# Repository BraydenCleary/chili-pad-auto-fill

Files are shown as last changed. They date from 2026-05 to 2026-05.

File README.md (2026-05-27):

# Chili Pad Auto-Fill

Automatically refills your [Chili Sleep](https://chilisleep.com) device's water reservoir once a day using an ESP32, a peristaltic pump, and a water level sensor. Just plug it in each morning and it checks the level and tops up if needed — no more waking up to a dry pad.

---

## How It Works

On power-up the ESP32 checks the water level sensor. If the reservoir is low it runs the peristaltic pump until the sensor reads full (or hits the 30-second safety timeout). Then it sleeps for 24 hours and repeats. Plug it in whenever you want the daily check to happen.

---

## Parts List

| Part | Notes |
|---|---|
| ESP32 dev board (WROOM) | Any standard 38-pin ESP32 works |
| [Kamoer 12V peristaltic pump](https://www.kamoer.com) | KPP-DC-S108 or similar |
| CQRobot optical water level sensor | Has a 3V/5V selector switch — set to 3V |
| 1-channel relay module (high/low level trigger) | Songle SRD-05VDC or similar |
| 12V 2A DC wall adapter | Barrel connector, cut off and strip the wires |
| Silicone tubing | Match your pump's tube diameter |
| WAGO 222-412 lever connectors | For joining pump and adapter ground wires |
| Male-to-male jumper wires | For connecting pump terminals to relay |
| Female-to-male jumper wires | For connecting sensor and relay to ESP32 |

---

## Wiring

### Sensor → ESP32
| Sensor wire | ESP32 pin |
|---|---|
| Red (VCC) | 3V3 |
| Black (GND) | GND |
| Green (signal) | P23 |

⚠️ Make sure the selector switch on the sensor is set to **3V** or it won't respond.

### Relay control side → ESP32
| Relay terminal | ESP32 pin |
|---|---|
| DC+ | 5V (VIN) |
| DC- | GND |
| IN | P22 |

### Relay switch side → pump (12V circuit)
| From | To |
|---|---|
| 12V adapter `+` (red wire) | Relay `COM` |
| Relay `NO` | Pump terminal 1 (via jumper wire) |
| 12V adapter `−` (black wire) | Pump terminal 2 (via WAGO connector) |

⚠️ The 12V circuit is electrically isolated from the ESP32 — do not connect the 12V ground to the ESP32 ground.

---

## Setup

### 1. Install MicroPython on the ESP32

1. Download and install [Thonny IDE](https://thonny.org)
2. Plug in your ESP32 via USB
3. In Thonny: **Run → Configure interpreter → MicroPython (ESP32)**
4. Click **Install or update MicroPython**
5. Select variant: **Espressif ESP32 / WROOM**, version **1.28.0**
6. Hit **Install** and wait ~30 seconds
7. You should see `>>>` in the Thonny shell when done

### 2. Configure the script

Open `main.py` and adjust these settings at the top if needed:

```python
MAX_RUN_S = 30   # max pump runtime in seconds -- set to ~2x a normal fill time
SENSOR_WET = 1   # 1 = sensor reads high when wet (confirmed for CQRobot optical)
```

### 3. Flash to the ESP32

1. In Thonny: **File → Save as → MicroPython device**
2. Name it exactly `main.py`
3. Hit OK

The ESP32 will now run the script automatically every time it powers up — no laptop needed.

---

## Usage

1. Fill a water jug and run the pump's inlet tube into it
2. Run the outlet tube into the Chili device's fill port
3. Submerge the sensor probe in the Chili reservoir
4. Plug the ESP32 into any USB power source
5. Plug the 12V adapter into the wall

The system checks the level immediately on power-up, pumps if needed, then sleeps 24 hours. Plug it in each morning at the time you want the daily refill to happen.

---

## Troubleshooting

**Sensor always reads the same value**
- Check the 3V/5V selector switch on the sensor — it must match your power pin
- Make sure the signal wire is on P23, not the adjacent GND pin

**Relay doesn't click**
- Confirm DC+ is on the ESP32's 5V/VIN pin, not 3.3V — the relay coil needs 5V
- Check the high/low trigger jumper on the relay board

**Pump runs backwards**
- Swap the two pump terminal wires — peristaltic pumps are reversible

**Pump runs but no water moves**
- Make sure the inlet tube is submerged in the water source
- Check for kinks in the tubing

---

## 3D Printed Parts

The file `chilisleep_cap_v2.stl` is a replacement cap for the Chili Sleep reservoir fill port — useful if your original cap is lost or damaged. It's a 133.5 × 133.5mm footprint, 5mm tall. Print in PLA or PETG with standard settings.

---

## License

MIT — do whatever you want with it.

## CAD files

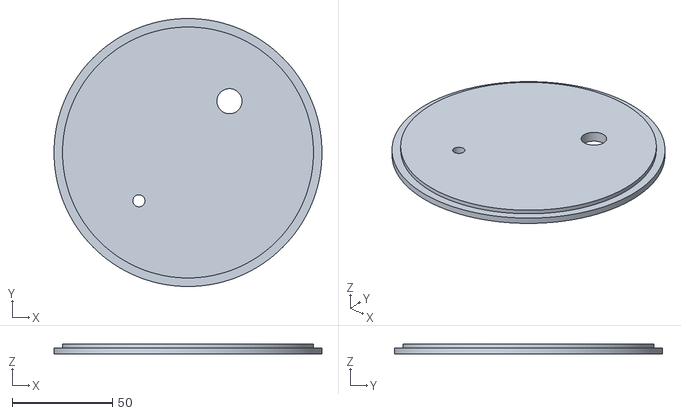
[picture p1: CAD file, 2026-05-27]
chili_pad_cap.stl
133.5 x 133.5 x 5.00

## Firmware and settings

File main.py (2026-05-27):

# Chili reservoir auto-fill -- ESP32 + MicroPython
# On power-up: check the level and pump if needed, then sleep 24 hours, repeat.

from machine import Pin
import time

# ---- CONFIG ----
RELAY_PIN  = 22
SENSOR_PIN = 23

RELAY_ON  = 1
RELAY_OFF = 0

SENSOR_WET = 1    # wet = 1, confirmed from testing
MAX_RUN_S  = 30   # flood failsafe -- never pump longer than this
# ----------------

relay  = Pin(RELAY_PIN, Pin.OUT)
sensor = Pin(SENSOR_PIN, Pin.IN, Pin.PULL_DOWN)

relay.value(RELAY_OFF)


def is_wet():
    return sensor.value() == SENSOR_WET


def fill():
    if is_wet():
        print("Level OK -- no fill needed")
        return
    print("Low water -> running pump")
    relay.value(RELAY_ON)
    start = time.ticks_ms()
    try:
        while True:
            if is_wet():
                print("Reached level -> stopping")
                break
            if time.ticks_diff(time.ticks_ms(), start) > MAX_RUN_S * 1000:
                print("TIMEOUT -> stopping (check water source / sensor)")
                break
            time.sleep(0.1)
    finally:
        relay.value(RELAY_OFF)


while True:
    print("Checking water level...")
    fill()
    print("Done. Sleeping 24 hours.")
    time.sleep(24 * 60 * 60)  # 24 hours in seconds
